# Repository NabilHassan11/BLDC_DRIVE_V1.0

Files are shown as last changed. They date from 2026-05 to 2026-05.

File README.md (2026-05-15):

# BLDC Drive

A 3-phase Brushless DC (BLDC) motor driver PCB designed in KiCad, capable of handling **12V** supply voltage at **10–25A** continuous phase current.

---

## 📸 Board Preview

<!-- Replace the placeholder below with your actual board image -->
<!-- > 📷 **[Insert top-view board photo or 3D render here]** -->

BLDC Drive Top View

---

## ✨ Features

- **Input Voltage:** 12V
- **Output Current:** 10–25A (per phase, depending on thermal management)
- **Gate Driver:** IR2110 half-bridge drivers (×3 — one per phase)
- **Power MOSFETs:** IRFZ44VZPBF N-channel MOSFETs in a 3-phase full-bridge configuration (6× total)
- **Current Sensing:** INA180A3 rail-to-rail current sense amplifiers
- **Bulk Decoupling:** 470µF electrolytic capacitors for supply filtering
- **EMI Filtering:** WE-CBF 0805 ferrite beads and 100nF bypass capacitors
- **Board Size:** 80mm × 80mm, 2-layer PCB
- **Connectors:** JST XH series
- **Designed with:** KiCad 8.0

---

## 🖼 Schematic

<!-- Add schematic image or PDF link below -->
> 📐 **[Insert schematic screenshot or link here]**

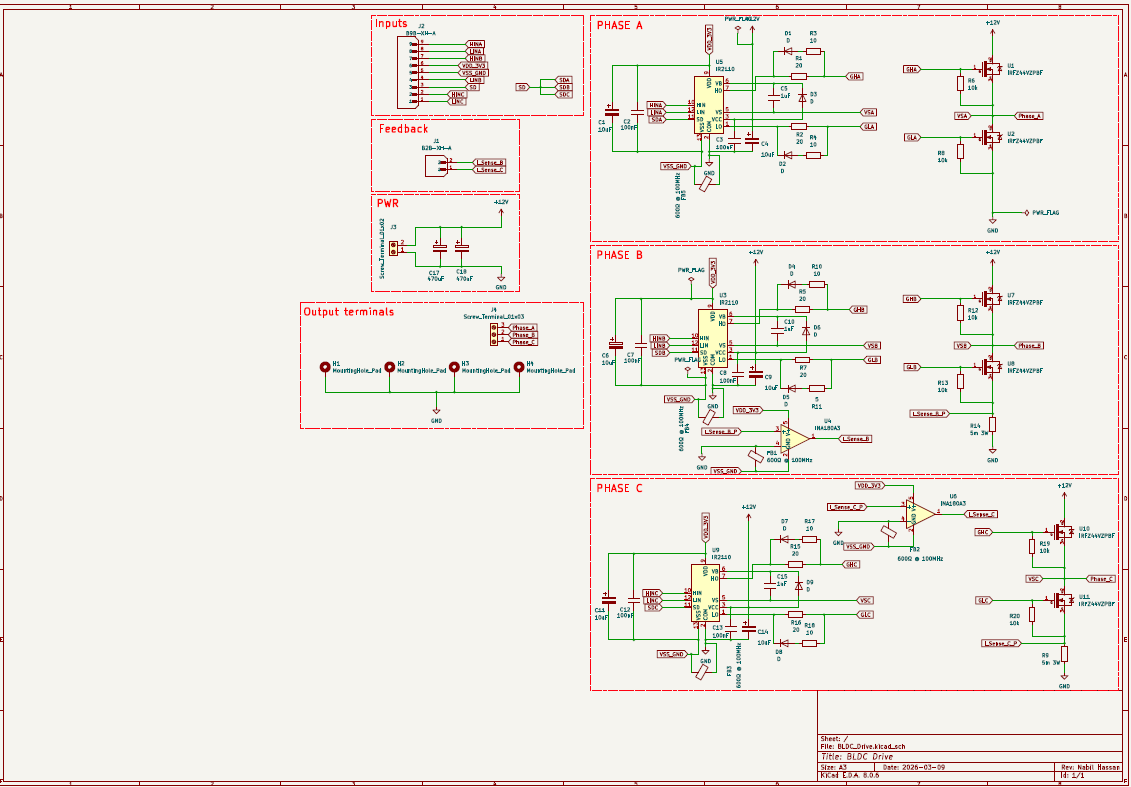
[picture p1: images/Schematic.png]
Schematic

<!-- Or link to the PDF: -->
<!-- [View Full Schematic (PDF)](BLDC_Drive/plots/BLDC_Drive__Assembly.pdf) -->
-->

---

## 🔩 Bill of Materials (BOM)

| Designator | Component | Value / Part Number | Description |
|---|---|---|---|
| Q1–Q6 | N-Channel MOSFET | IRFZ44VZPBF | Power switch, TO-220 |
| U1–U3 | Gate Driver | IR2110 | Half-bridge gate driver |
| U4–U6 | Current Sense Amp | INA180A3 | Rail-to-rail, 100V/V gain, SOT-23-5 |
| C_bulk | Electrolytic Cap | 470µF | Bulk supply decoupling |
| C_bypass | Ceramic Cap | 100nF | High-freq bypass |
| C_gate | Ceramic Cap | 1µF / 10µF | Gate drive bootstrap / filtering |
| R_sense | Shunt Resistor | 5mΩ 3W | Phase current sensing |
| R_gate | Resistor | 5Ω / 10Ω / 20Ω | Gate resistance |
| FB1–FBx | Ferrite Bead | WE-CBF 0805, 600Ω@100MHz | EMI filtering |
| J_motor | JST B9B-XH-A | 9-pin | Motor phase + hall sensor connector |
| J_signal | JST B2B-XH-A | 2-pin | Signal/control connector |
| — | Screw Terminals | 2-pin, 3-pin | Power input/output terminals |

> 📋 **Full interactive BOM:** [`BLDC_Drive/bom/ibom.html`](BLDC_Drive/bom/ibom.html)

---

## 📁 Repository Structure

```
BLDC_Drive/
├── BLDC_Drive/
│   ├── BLDC_Drive.kicad_sch         # Schematic
│   ├── BLDC_Drive.kicad_pcb         # PCB layout
│   ├── BLDC_Drive.kicad_pro         # KiCad project file
│   ├── bom/
│   │   └── ibom.html                # Interactive BOM
│   ├── Drill Files/                 # PTH and NPTH drill files
│   ├── gerber_to_order/             # Ready-to-order Gerbers
│   │   ├── BLDC_Drive_80.0x80.0mm_for_JLCPCB/
│   │   ├── BLDC_Drive_80.0x80.0mm_for_Elecrow/
│   │   ├── BLDC_Drive_80.0x80.0mm_for_PCBWay/
│   │   └── BLDC_Drive_80.0x80.0mm_for_FusionPCB/
│   └── plots/
│       └── BLDC_Drive__Assembly.pdf # Assembly drawing
├── AOD4184A/                        # KiCad library: AOD4184A MOSFET
├── IRFZ44VZPBF/                     # KiCad library: IRFZ44VZPBF MOSFET
├── LIB_DRV8353SRTAR/                # KiCad library: DRV8353 gate driver
├── B2B-XH-A/ & B9B-XH-A/           # KiCad library: JST connectors
├── LM358P/                          # KiCad library: LM358 op-amp
├── WE-CBF_0805/                     # KiCad library: ferrite bead
└── cap_calculator.jsx               # Bootstrap capacitor calculator tool
```

---

## 🖼 PCB Layout

<!-- Add PCB layout images below -->

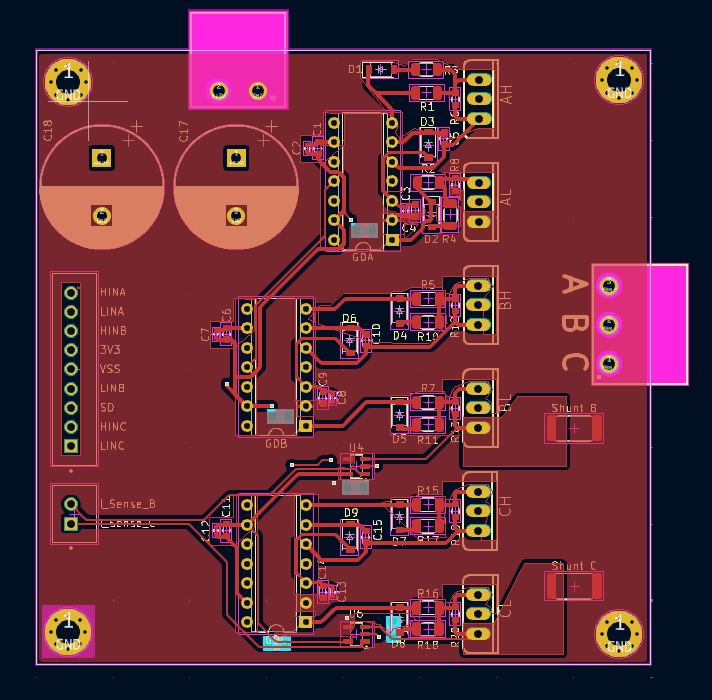
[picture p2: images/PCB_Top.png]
PCB Top Layer

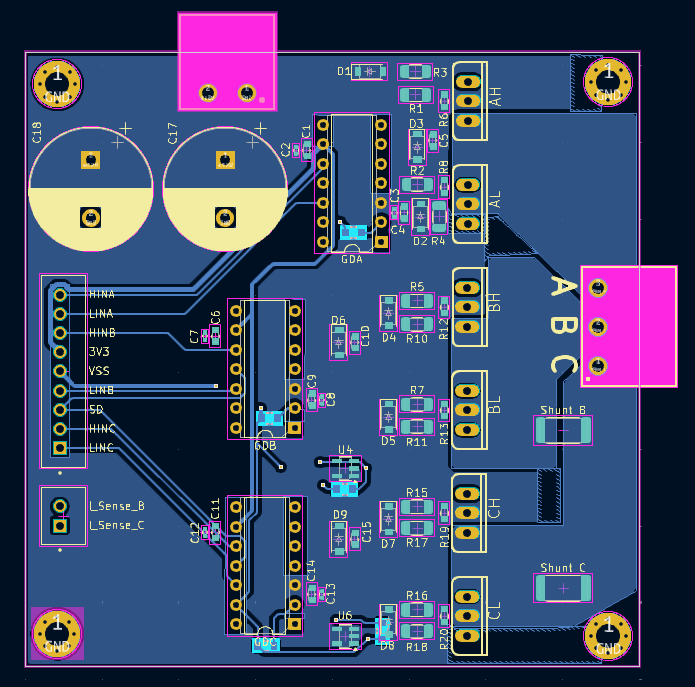
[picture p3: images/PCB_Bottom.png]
PCB Bottom Layer


---

## 🚀 Getting Started

### Requirements

- [KiCad 8.0](https://www.kicad.org/) or later
- A 12V DC power supply rated for at least 25A
- PWM control signals (typically from a microcontroller or dedicated BLDC controller)

### Opening the Project

1. Clone or download this repository.
2. Open KiCad and select **File → Open Project**.
3. Navigate to `BLDC_Drive/BLDC_Drive.kicad_pro`.
4. Import the custom component libraries from the component folders (see `how-to-import.htm` inside each folder).

### Ordering PCBs

Pre-generated Gerber files are available for major manufacturers inside `BLDC_Drive/gerber_to_order/`. Simply upload the appropriate `.zip` file to your fab of choice:

| Manufacturer | Gerber Package |
|---|---|
| JLCPCB | `BLDC_Drive_80.0x80.0mm_for_JLCPCB.zip` |
| PCBWay | `BLDC_Drive_80.0x80.0mm_for_PCBWay.zip` |
| Elecrow | `BLDC_Drive_80.0x80.0mm_for_Elecrow.zip` |
| FusionPCB | `BLDC_Drive_80.0x80.0mm_for_FusionPCB.zip` |

Recommended PCB specs: **2 layers, 2oz copper, HASL or ENIG finish.**

---

## ⚡ Electrical Specifications

| Parameter | Value |
|---|---|
| Supply Voltage (V_bus) | 12V |
| Continuous Phase Current | 10–25A |
| MOSFET V_DS rating | 60V (IRFZ44VZPBF) |
| MOSFET I_D rating | 55A (IRFZ44VZPBF) |
| Gate Driver Bootstrap voltage | 12V |
| Current sense gain | 100 V/V (INA180A3) |
| Shunt resistance | 5mΩ |

---

## ⚠️ Warnings & Safety Notes

- Always ensure proper heat sinking on the power MOSFETs (Q1–Q6) when operating above 10A.
- Do not exceed **12V** on the V_bus input without verifying all component voltage ratings.
- Verify gate drive bootstrap capacitor values using the included `cap_calculator.jsx` tool before assembling.
- The board does not include overcurrent protection hardware — implement this in firmware or add an external fuse rated for your load.
- This board is designed for **DC brushless motors only**. Do not connect it to AC loads.

---

## 🔧 Assembly Notes

> 🔩 **[Insert assembled board photo here]**

<!-- Example:
![Assembled Board](images/assembled.jpg)
-->

- Begin soldering with the smallest SMD components first (ferrite beads, bypass caps, SOT-23 ICs).
- Solder power MOSFETs and screw terminals last.
- Refer to the interactive BOM (`bom/ibom.html`) for component placement guidance.
- The assembly drawing PDF (`plots/BLDC_Drive__Assembly.pdf`) can be printed as a reference during assembly.

---

## 👤 Author

**Nabil Hassan**
Revision date: 2026-03-09

---

## 🤝 Contributing

Pull requests and issue reports are welcome. If you find a bug in the schematic or layout, please open an issue with a description and reference designators.

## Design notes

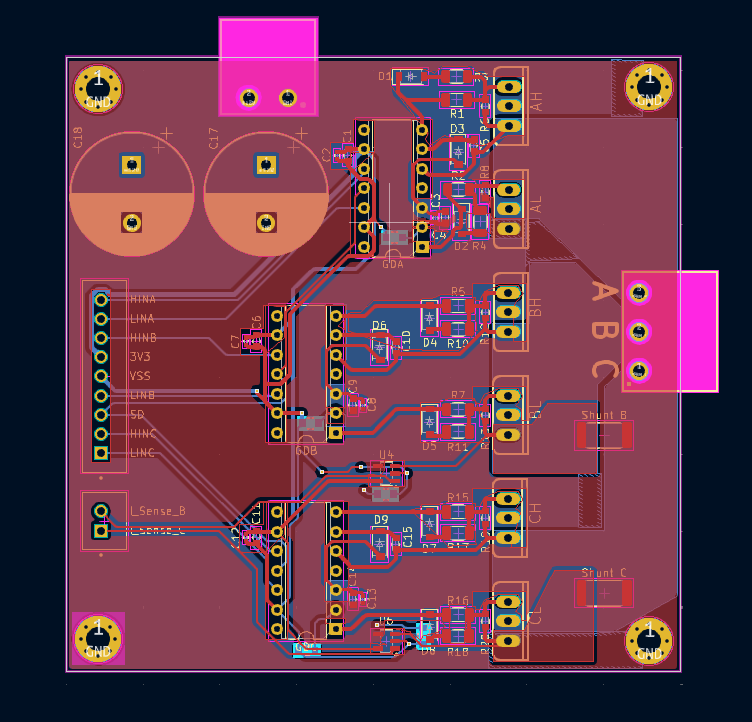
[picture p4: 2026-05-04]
images/PCB.png

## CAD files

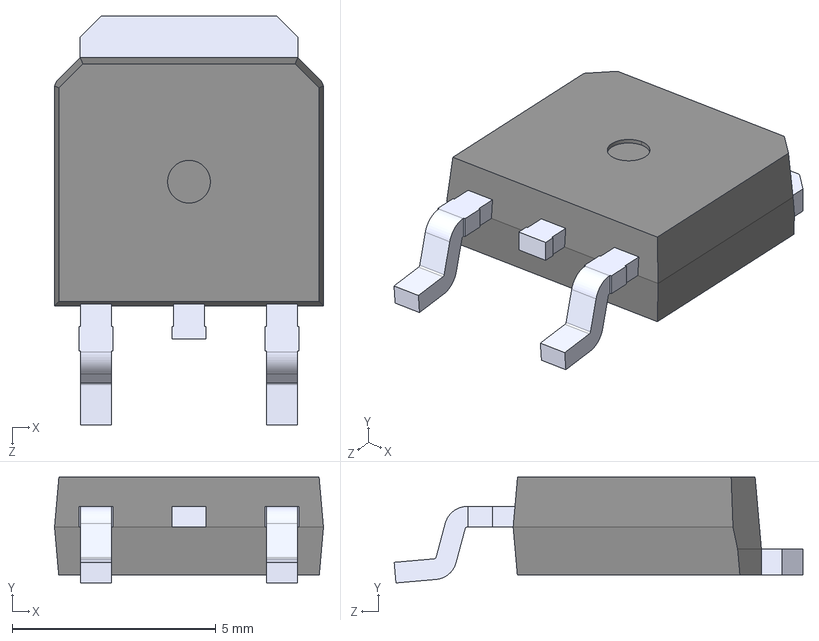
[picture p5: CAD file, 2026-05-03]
AOD4184A/AOD4184A.step
6.60 x 2.60 x 10.0 mm

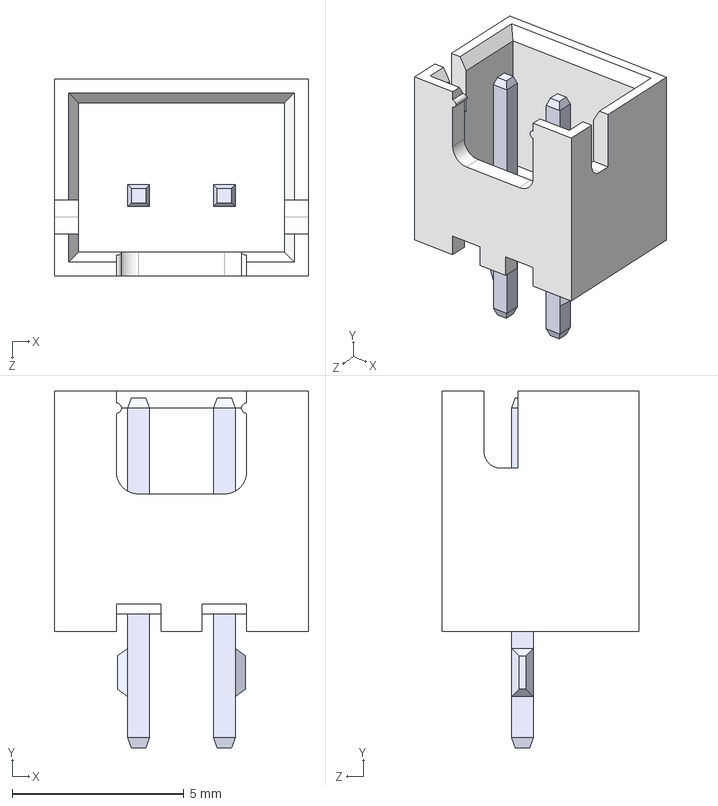
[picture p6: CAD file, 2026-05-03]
B2B-XH-A/B2B-XH-A.step
7.40 x 10.4 x 5.75 mm

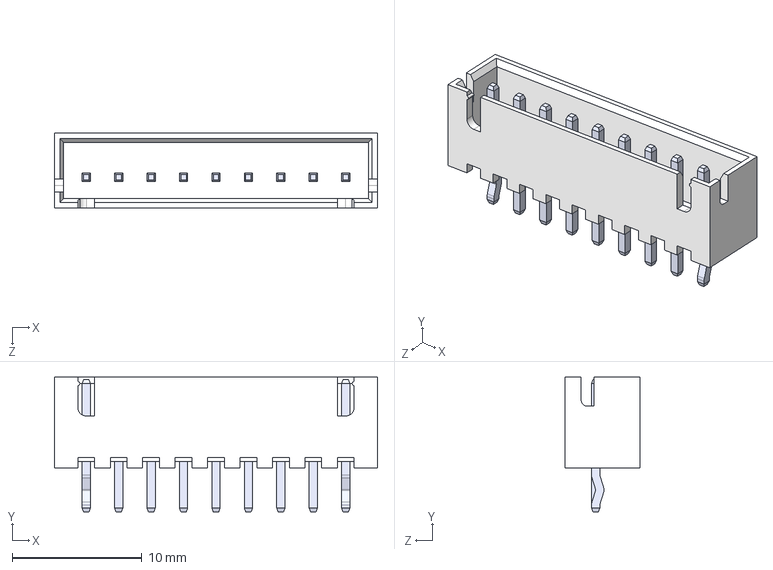
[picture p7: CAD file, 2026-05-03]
B9B-XH-A/B9B-XH-A.step
24.9 x 10.4 x 5.75 mm

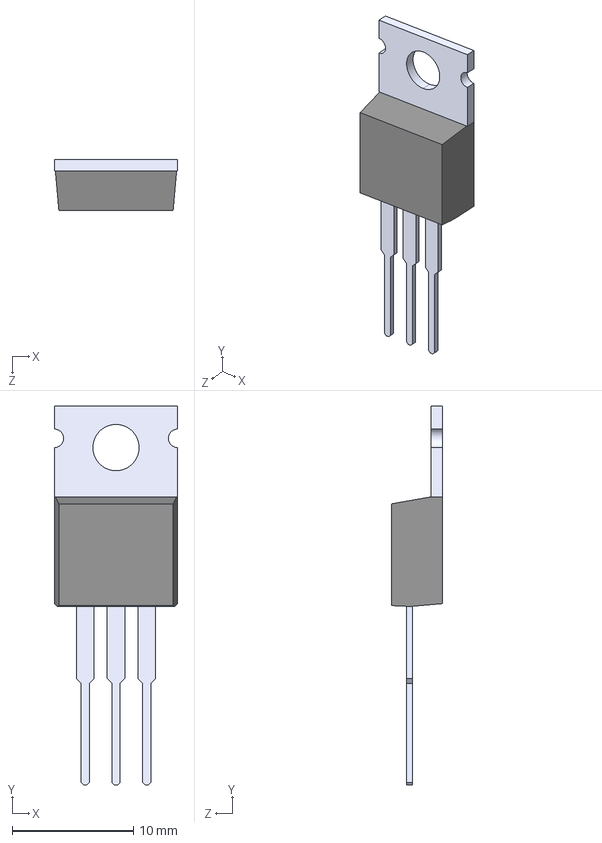
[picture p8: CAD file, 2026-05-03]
IRFZ44VZPBF/IRFZ44VZPBF.step
10.2 x 31.2 x 4.19 mm

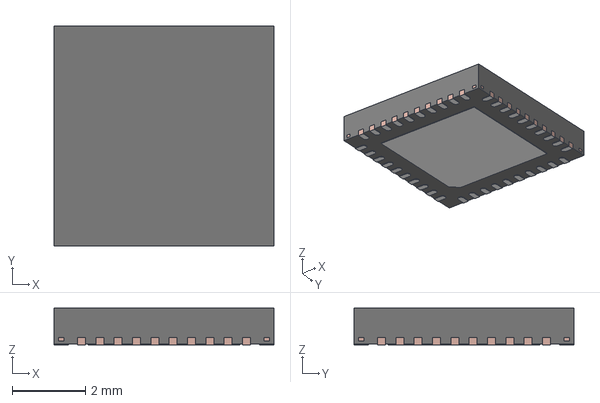
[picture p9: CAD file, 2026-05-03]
LIB_DRV8353SRTAR/DRV8353SRTAR/3D/DRV8353SRTAR.stp
6.00 x 6.00 x 1.00 mm
FRAME

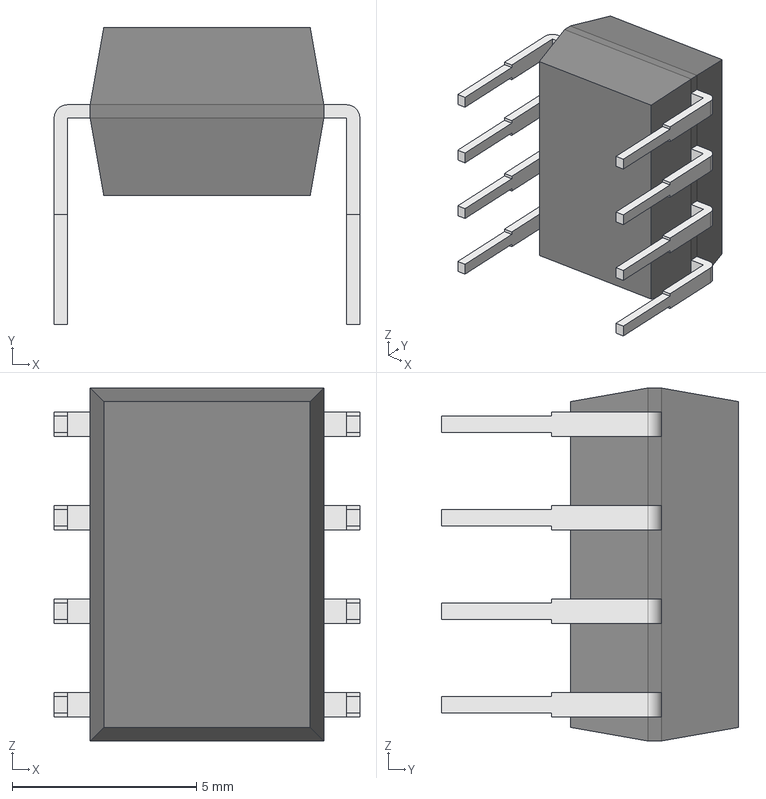
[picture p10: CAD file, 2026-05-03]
LM358P/LM358P.step
8.31 x 8.08 x 9.59 mm
Body001 (Mirror #1) x 5

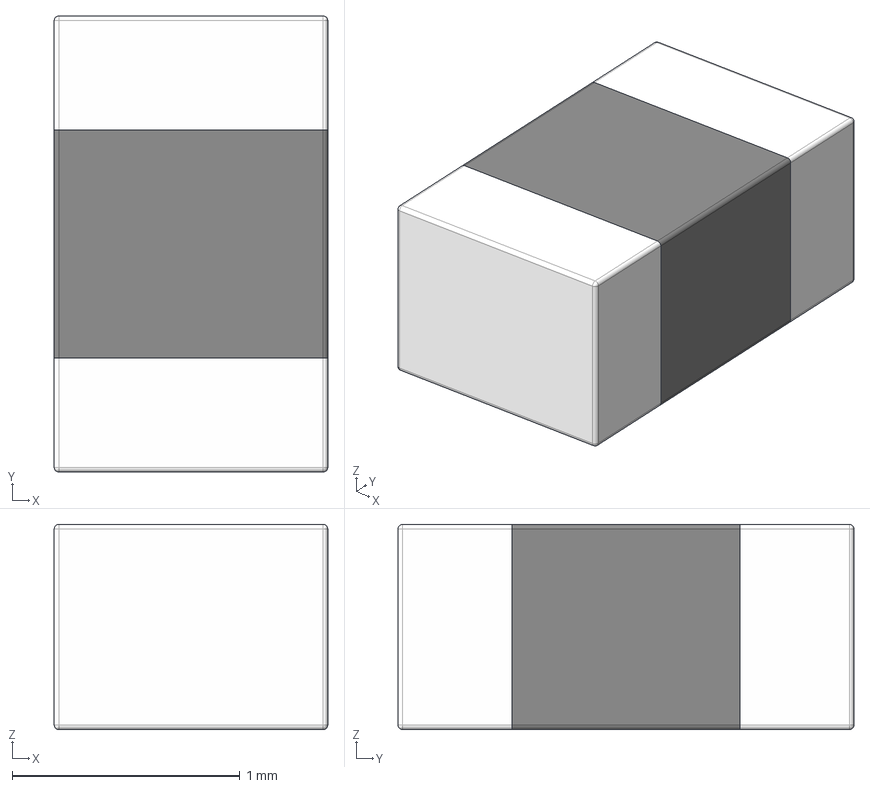
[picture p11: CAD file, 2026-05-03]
WE-CBF_0805/WE-CBF_0805.step
1.20 x 2.00 x 0.9 mm
Lötende x 2

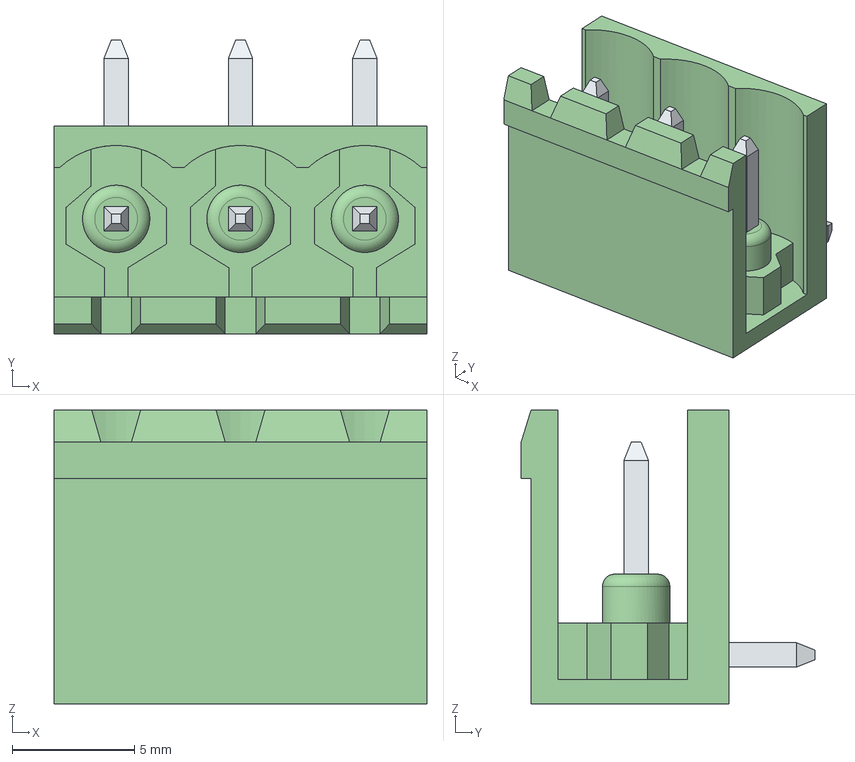
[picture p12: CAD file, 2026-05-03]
691312510003/691312510003.step
15.2 x 12.0 x 12.0 mm
6913125100xx_PIN x 3

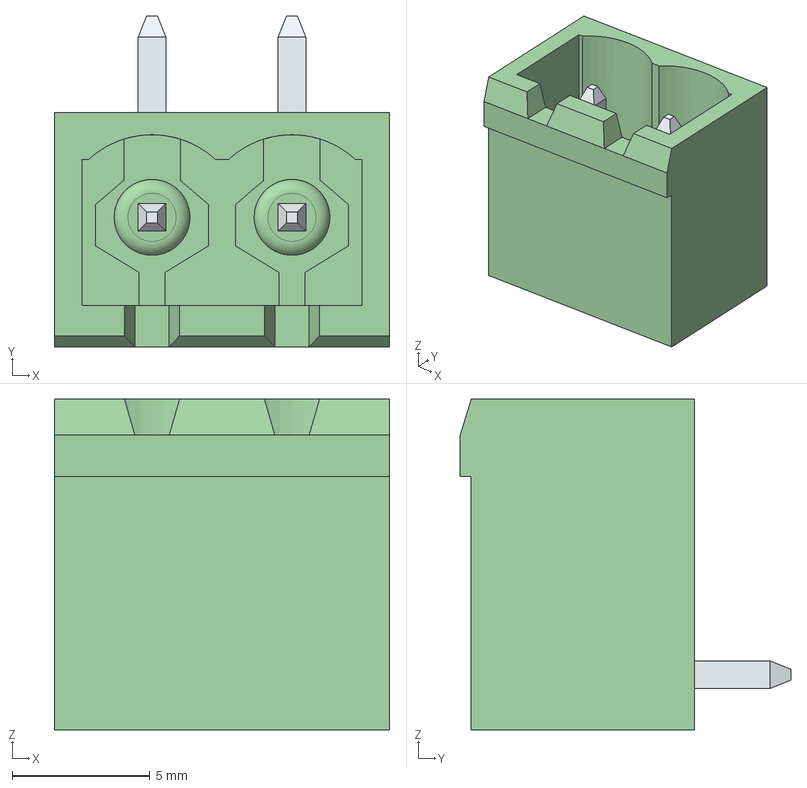
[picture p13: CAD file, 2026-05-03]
691313510002/691313510002.step
12.2 x 12.0 x 12.0 mm
6913135100xx_PIN x 2

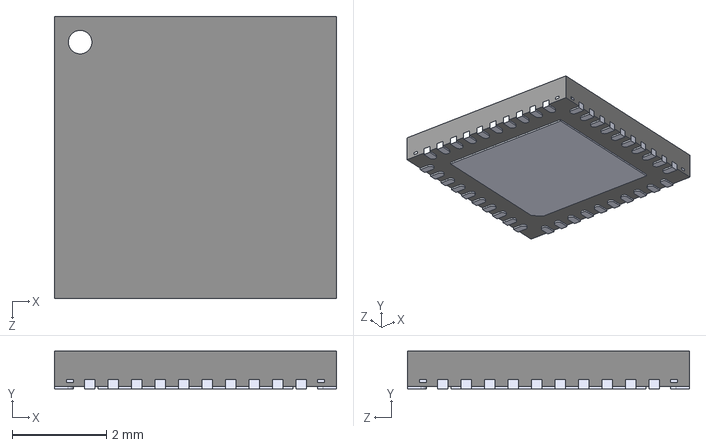
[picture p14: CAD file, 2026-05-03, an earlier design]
LIB_DRV8353SRTAR (1)/DRV8353SRTAR/KiCad/QFN50P600X600X80-41N/QFN50P600X600X80-41N.step
6.00 x 0.8 x 6.00 mm

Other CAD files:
LIB_DRV8353SRTAR (1)/DRV8353SRTAR/Allegro/qfn50p600x600x80-41n-d.psm
LIB_DRV8353SRTAR (1)/DRV8353SRTAR/DEHDL/drv8353srtar/chips/chips.prt
LIB_DRV8353SRTAR/DRV8353SRTAR/Allegro/qfn50p600x600x80-41n-d.psm
LIB_DRV8353SRTAR/DRV8353SRTAR/DEHDL/drv8353srtar/chips/chips.prt

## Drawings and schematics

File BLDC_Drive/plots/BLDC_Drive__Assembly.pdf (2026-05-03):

# GDC BL CH AH

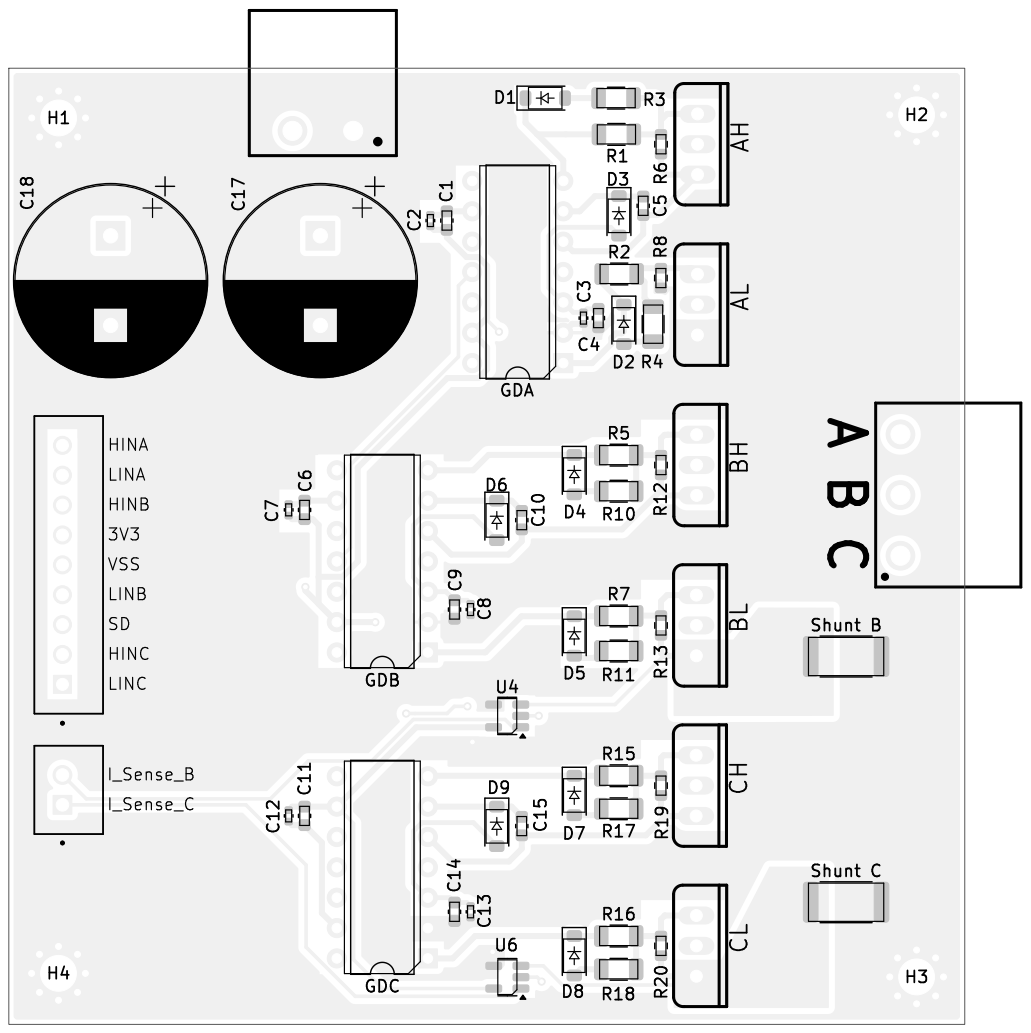
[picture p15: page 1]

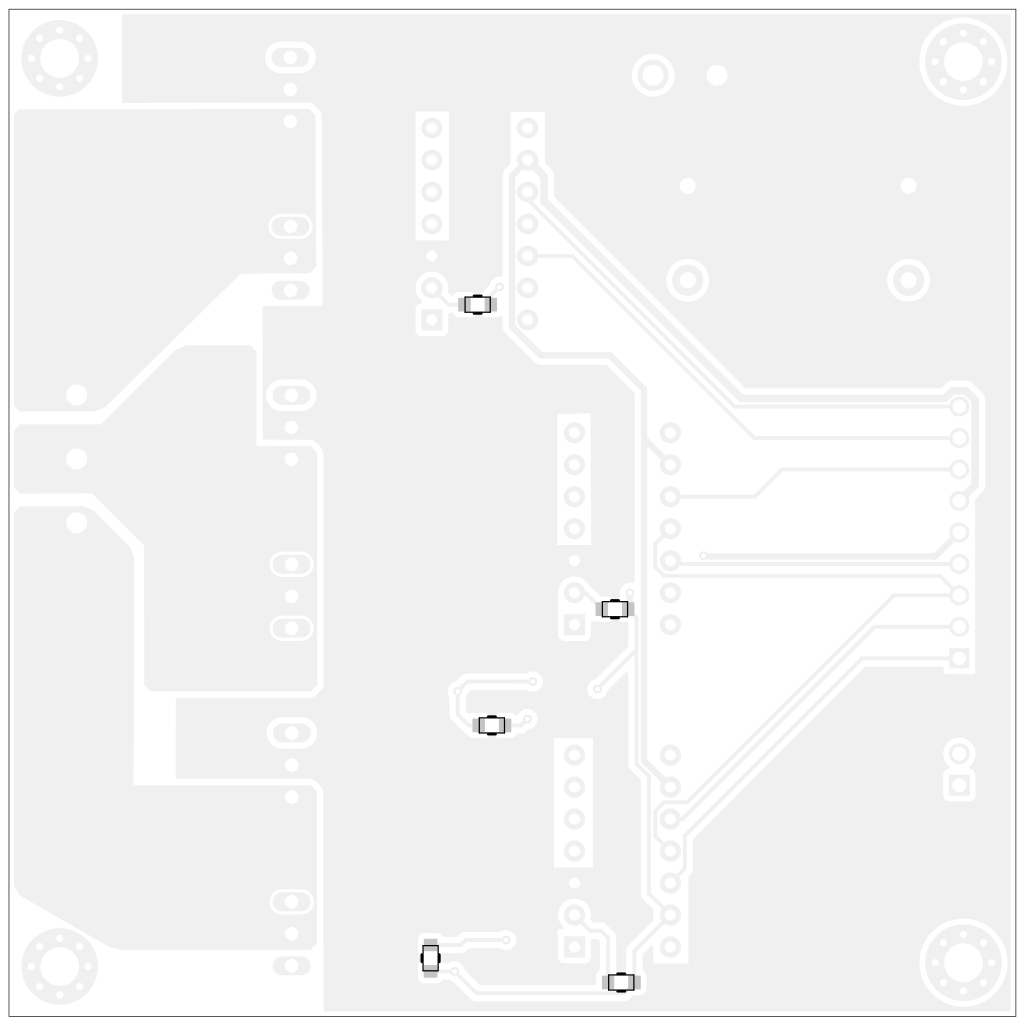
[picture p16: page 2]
D Date: KiCad; E.D.A. 8.0.6 Size: A4; Rev:; Id: 1/1 Title: File: BLDC_Drive.kicad_pcb Sheet: Black; And; White; BOT Board2Pdf:; Black; BOT -; Page 2/8

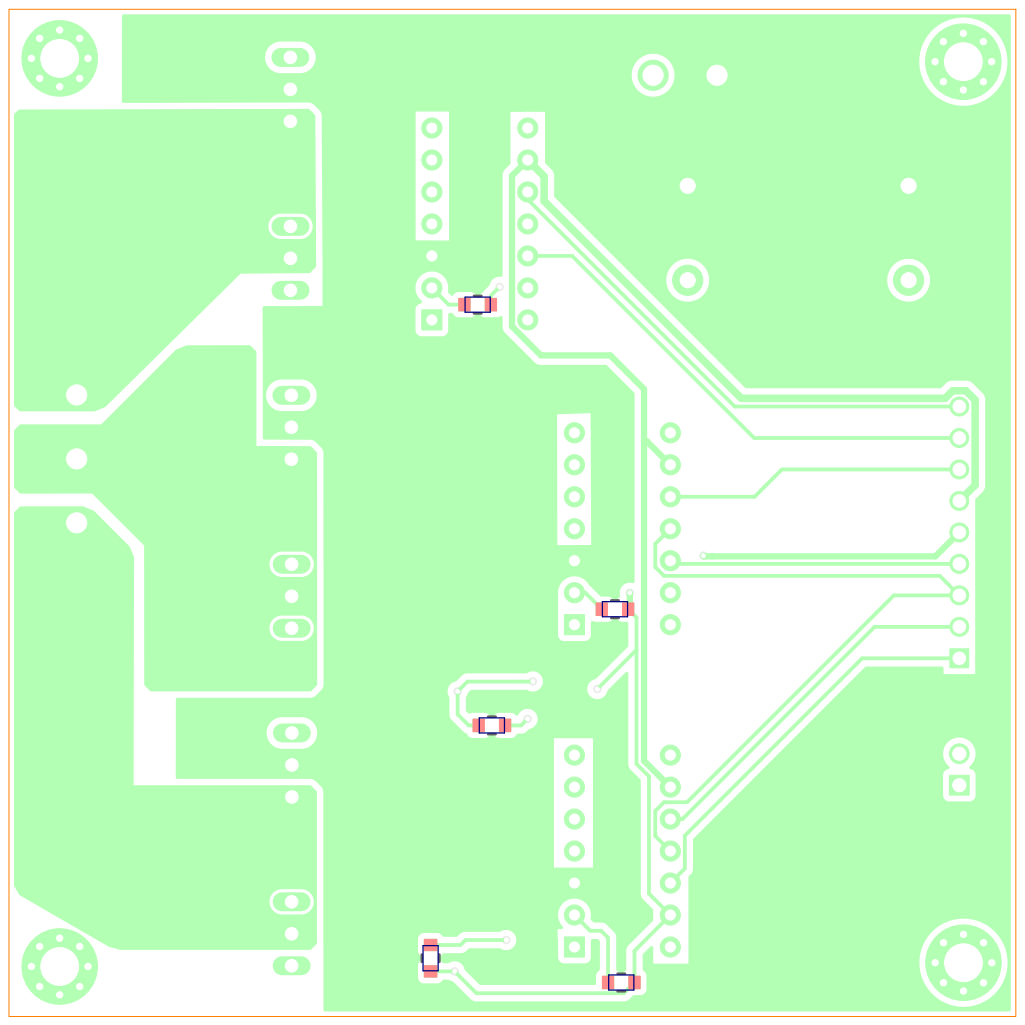
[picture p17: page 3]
D Date: KiCad; E.D.A. 8.0.6 Size: A4; Rev:; Id: 1/1 Title: File: BLDC_Drive.kicad_pcb Sheet: Colored; BOT Board2Pdf:; Colored; BOT -; Page 3/8

# GDC BL CH AH

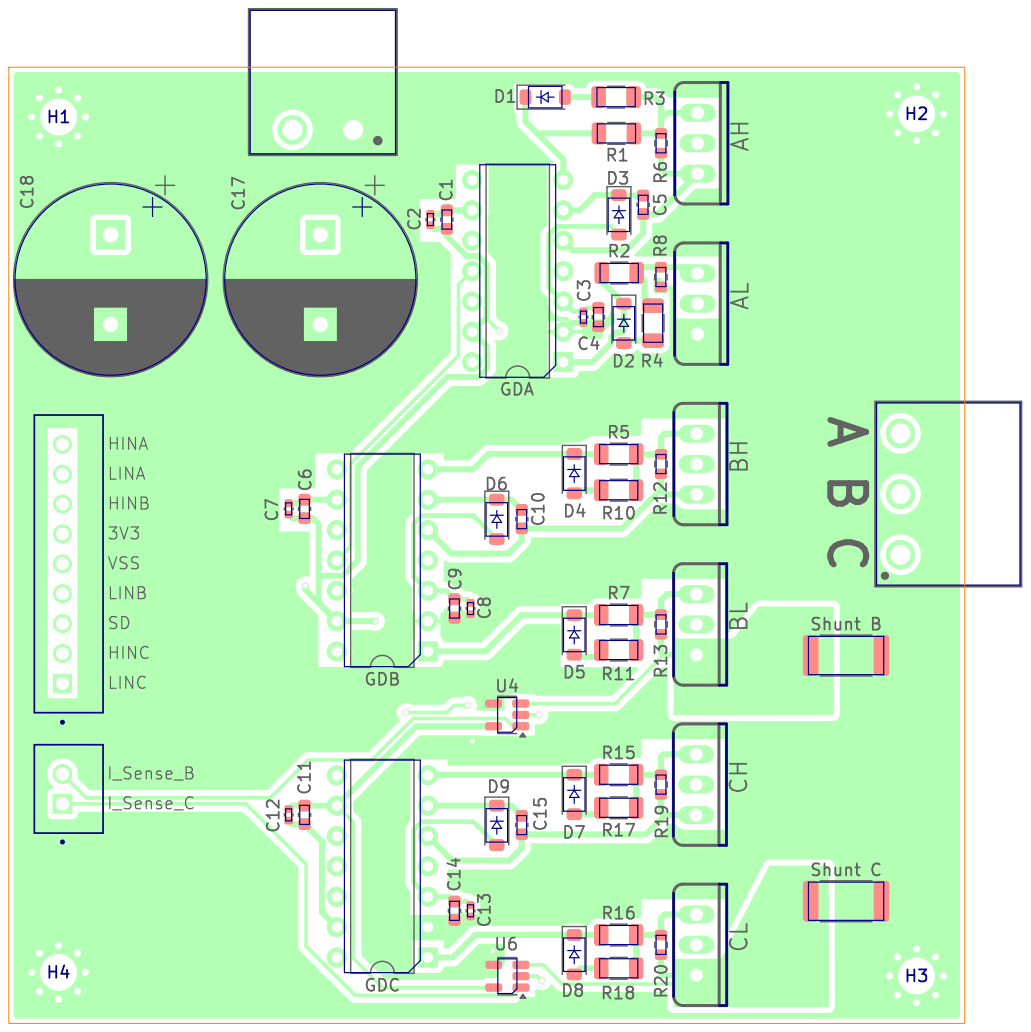
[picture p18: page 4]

# GDC BL CH AH

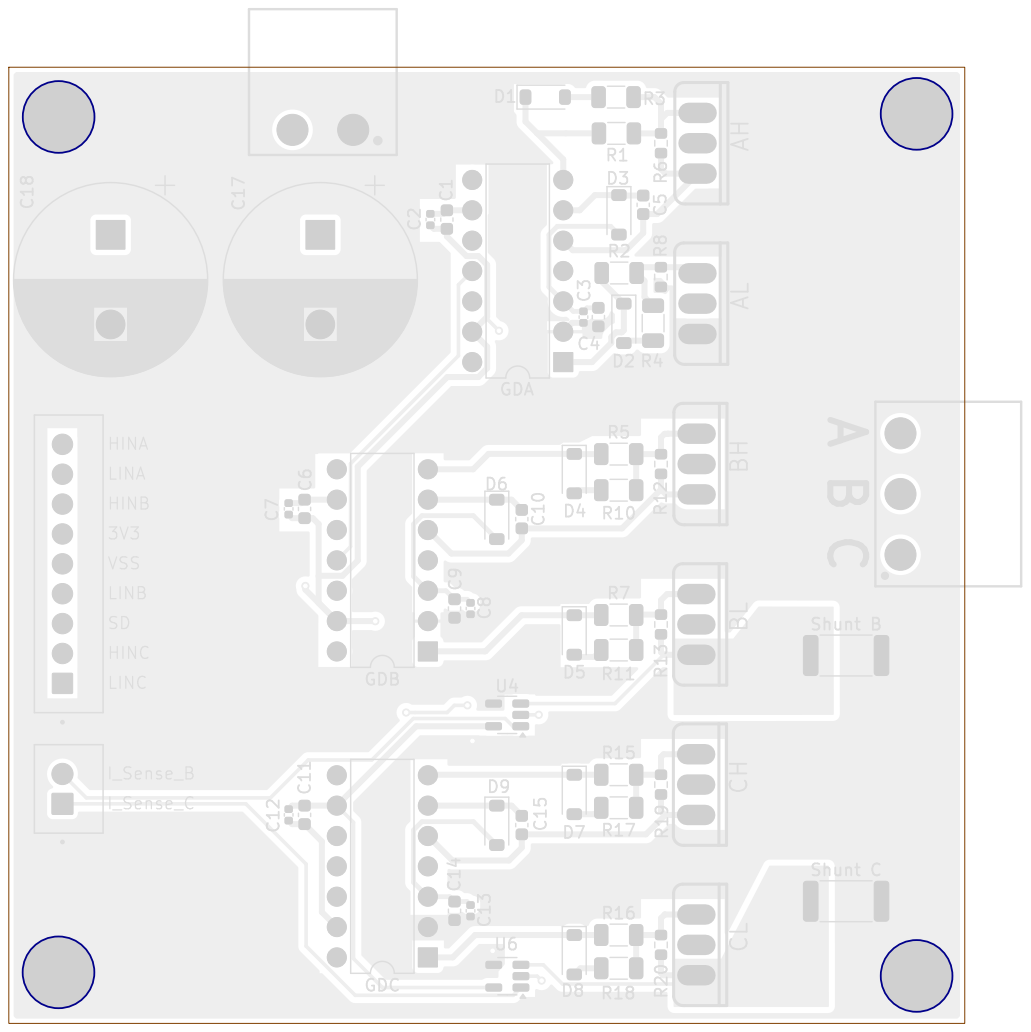
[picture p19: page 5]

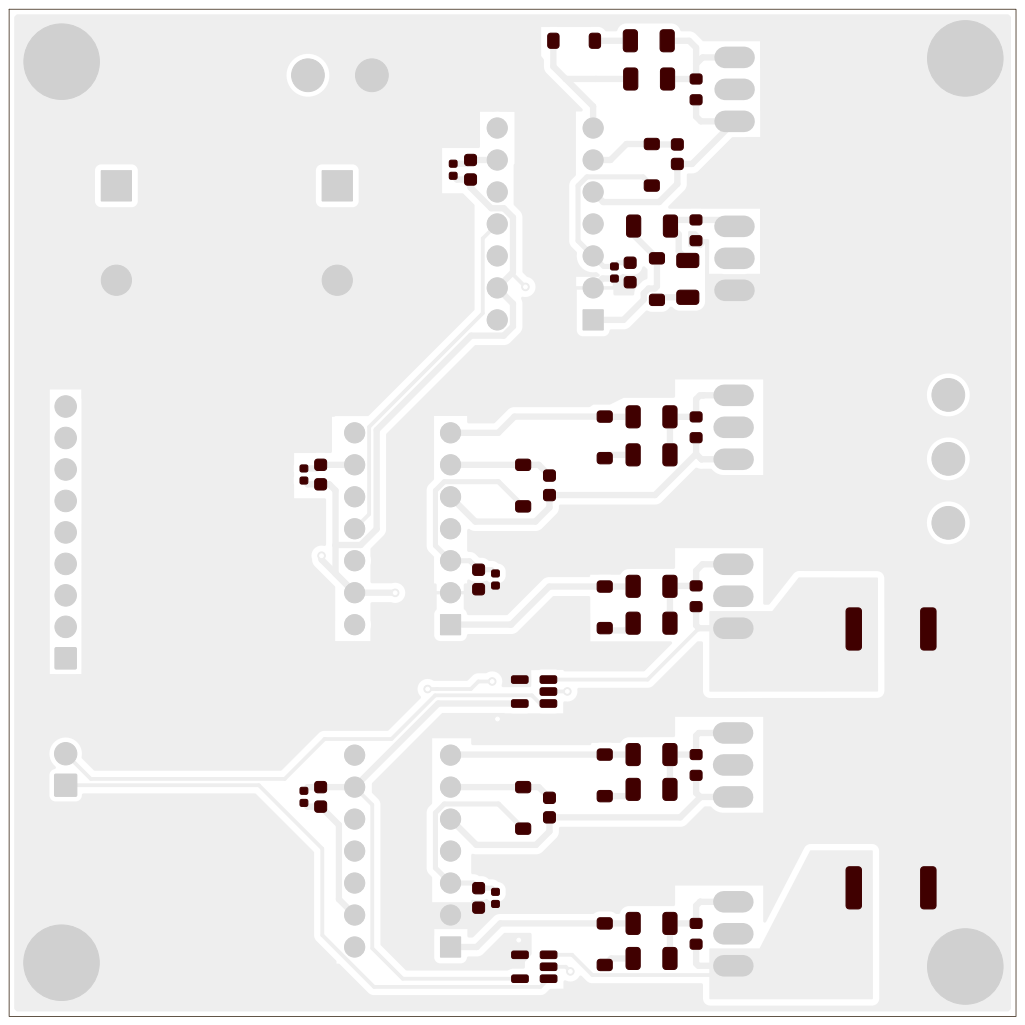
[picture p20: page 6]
D Date: KiCad; E.D.A. 8.0.6 Size: A4; Rev:; Id: 1/1 Title: File: BLDC_Drive.kicad_pcb Sheet: Light Colors; PCB; Paste; TOP; Board2Pdf:; Light Colors; TOP -; Page 6/8

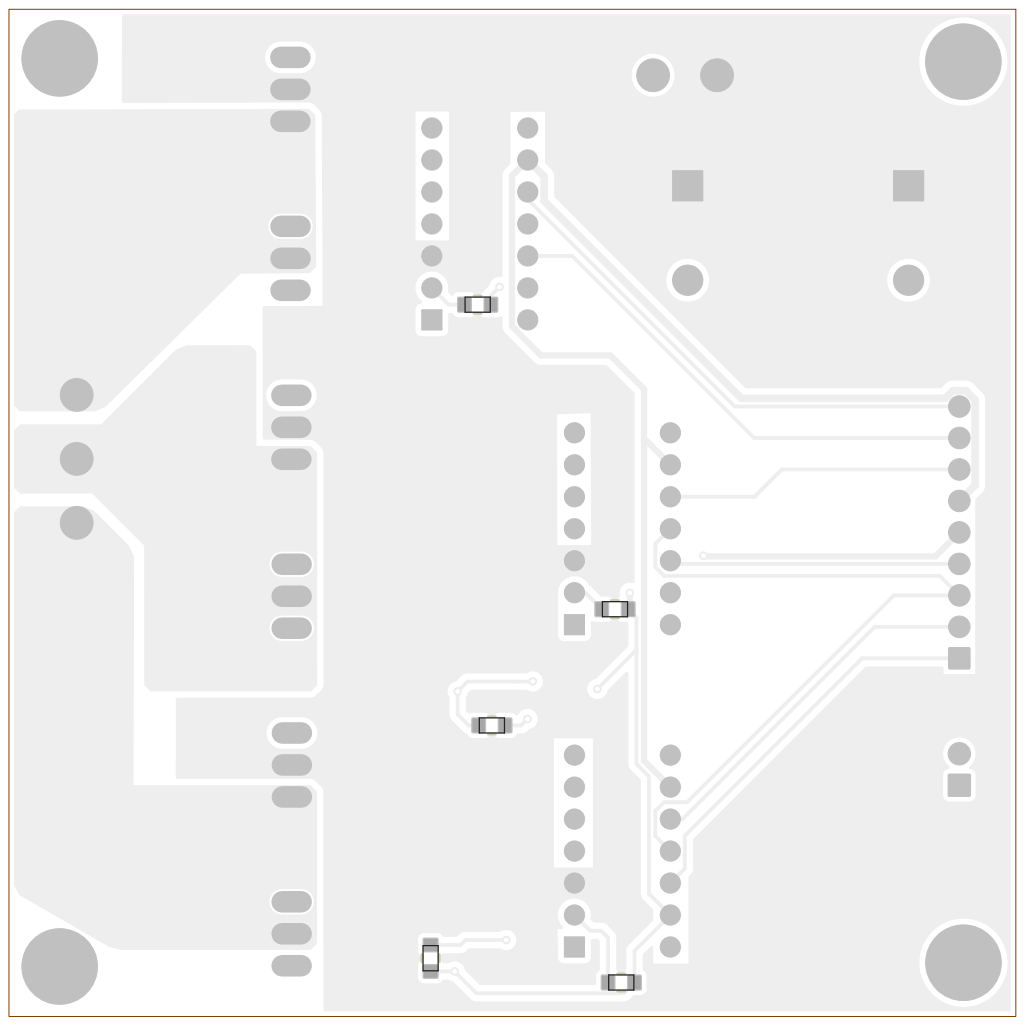
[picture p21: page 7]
D Date: KiCad; E.D.A. 8.0.6 Size: A4; Rev:; Id: 1/1 Title: File: BLDC_Drive.kicad_pcb Sheet: Light Colors; Placement; BOT Board2Pdf:; Light Colors; BOT -; Page 7/8

# GDC BL CH AH

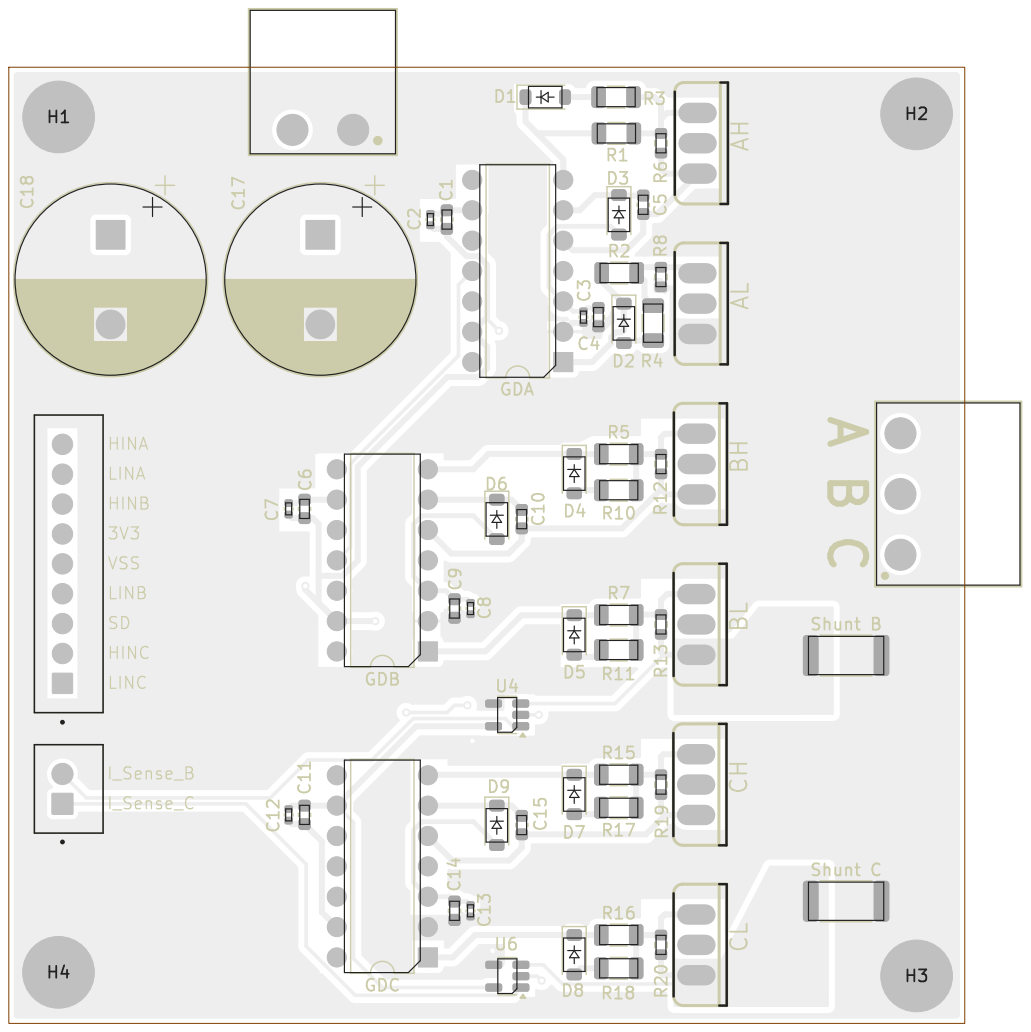
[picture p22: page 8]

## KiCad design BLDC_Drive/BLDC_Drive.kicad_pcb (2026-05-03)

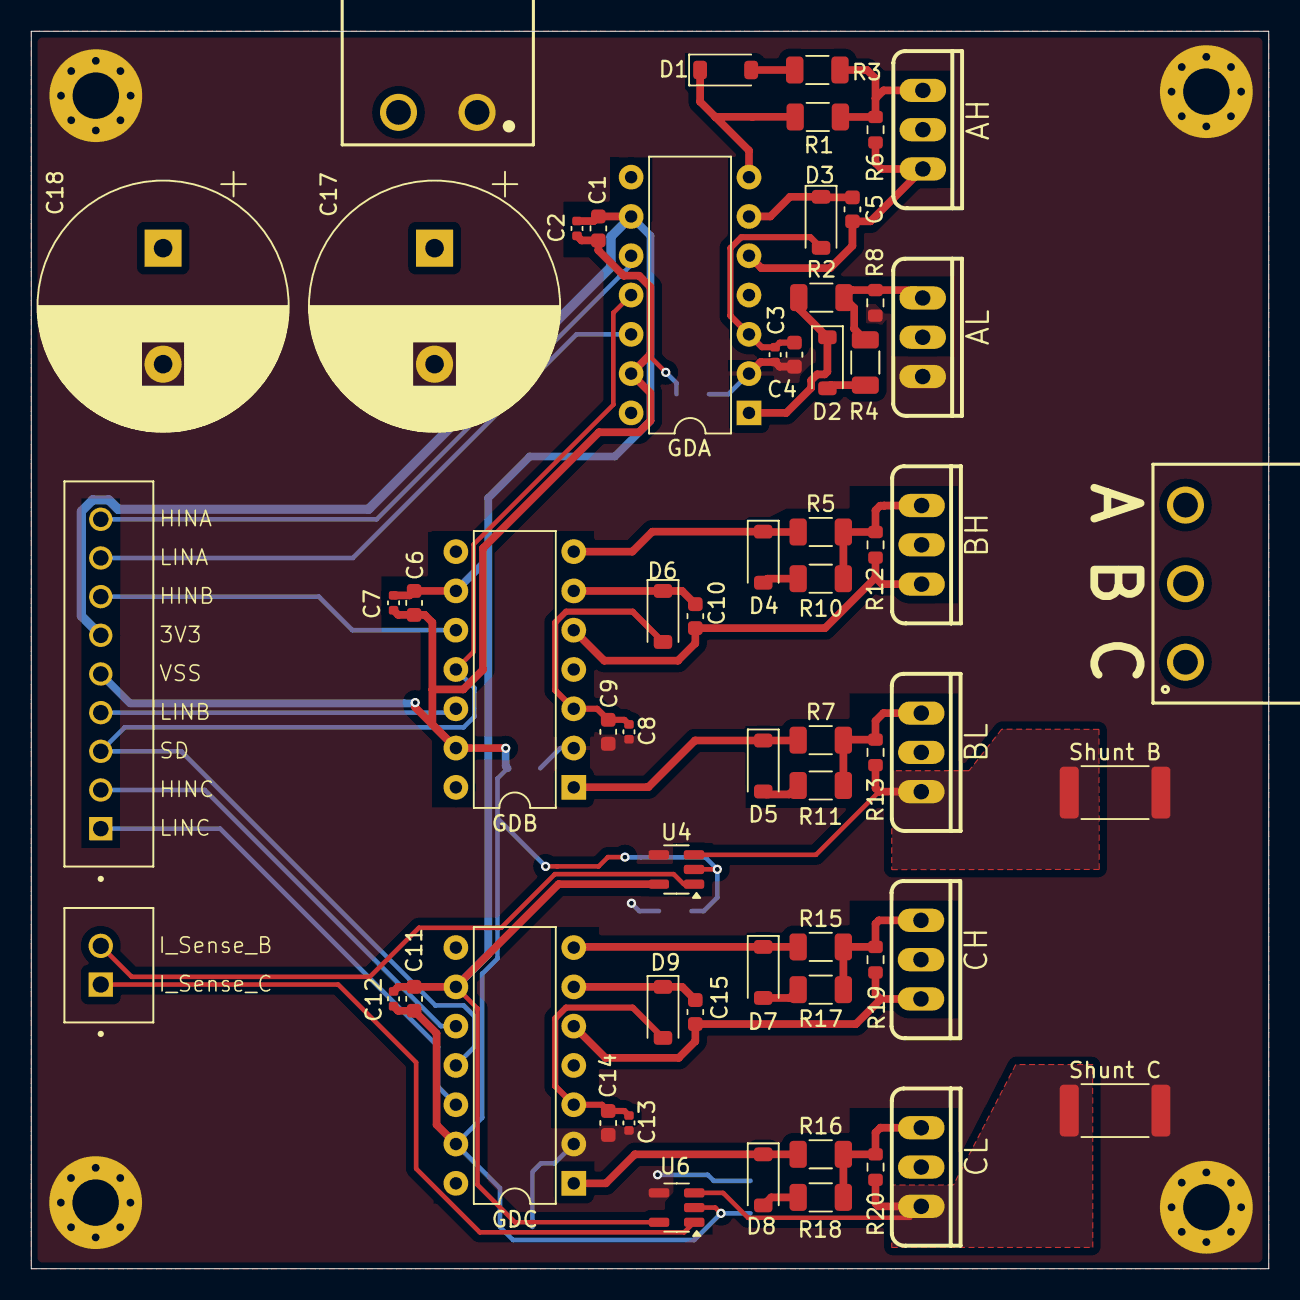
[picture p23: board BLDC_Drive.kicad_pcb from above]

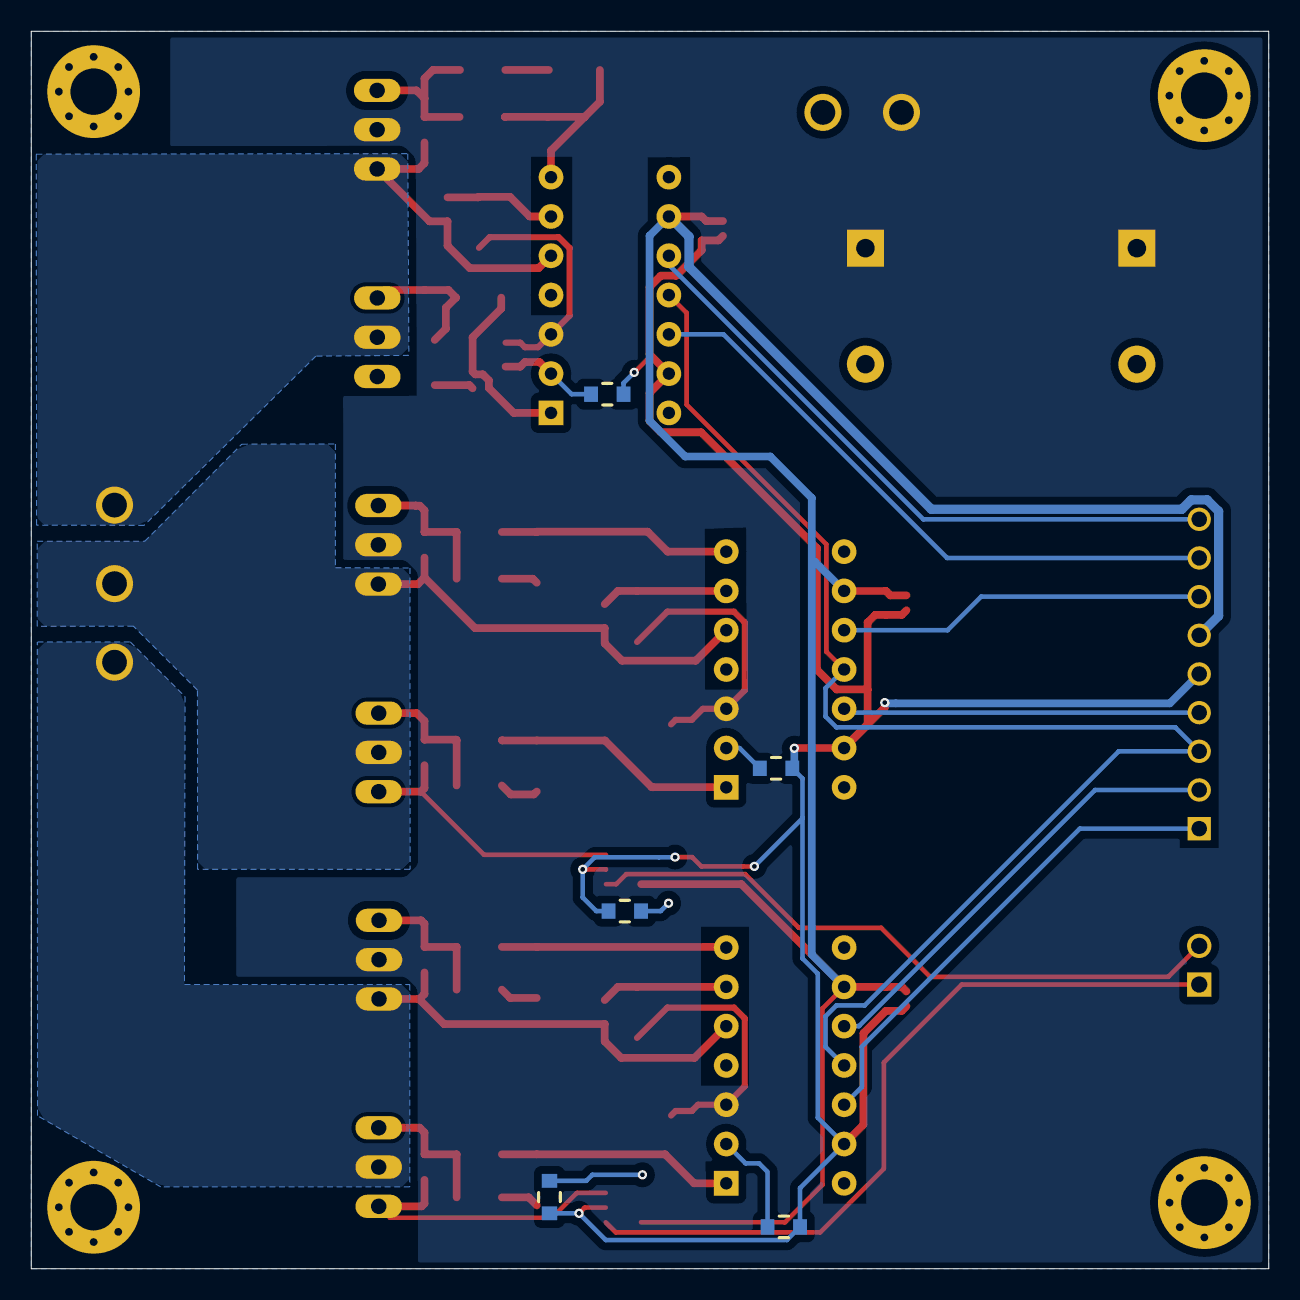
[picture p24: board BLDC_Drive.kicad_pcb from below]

Board: 2 copper layers, 80.0 x 80.0 mm, 70 parts (5 on the bottom side), 39 nets.

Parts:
AH: IRFZ44VZPBF; TO-220
AL: IRFZ44VZPBF; TO-220
BH: IRFZ44VZPBF; TO-220
BL: IRFZ44VZPBF; TO-220
C1, C4, C6, C9, C11, C14: 10uF; C_0603_1608Metric
C2, C3, C7, C8, C12, C13: 100nF; C_0402_1005Metric
C5, C10, C15: 1uF; C_0603_1608Metric
C17, C18: 470uF; CP_Radial_D16.0mm_P7.50mm
CH: IRFZ44VZPBF; TO-220
CL: IRFZ44VZPBF; TO-220
D1, D2, D3, D4, D5, D6, D7, D8, D9: D; D_SOD-123
FB1, FB2, FB3, FB4, FB5: 600Ω @ 100MHz; WE-CBF_0805_W3.0
GDA: IR2110; DIP-14_W7.62mm
GDB: IR2110; DIP-14_W7.62mm
GDC: IR2110; DIP-14_W7.62mm
H1, H2, H3, H4: MountingHole_Pad; MountingHole_3mm_Pad_Via
J1: B2B-XH-A; JST_B2B-XH-A
J2: B9B-XH-A; JST_B9B-XH-A
J3: Screw_Terminal_01x02; 691313510002
J4: Screw_Terminal_01x03; 691312510003
R1, R2, R5, R7, R15, R16: 20; R_1206_3216Metric
R3, R4, R10, R17, R18: 10; R_1206_3216Metric
R6, R8, R12, R13, R19, R20: 10k; R_0603_1608Metric
R11: 5; R_1206_3216Metric
Shunt B: 5m 3W; R_2512_6332Metric
Shunt C: 5m 3W; R_2512_6332Metric
U4, U6: INA180A3; SOT-23-5

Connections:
+12V: AH.2, BH.2, C3.1, C4.1, C8.1, C9.1, C13.1, C14.1, C17.1, C18.1, CH.2, D3.2 (A), D6.2 (A), D9.2 (A), GDA.3 (VCC), GDB.3 (VCC), GDC.3 (VCC), J3.2
GHA: AH.1, R1.2, R3.2, R6.1
GHB: BH.1, R5.2, R10.2, R12.1
GHC: CH.1, R15.2, R17.2, R19.1
GLA: AL.1, R2.2, R4.1, R8.1
GLB: BL.1, R7.2, R11.1, R13.1
GLC: CL.1, R16.2, R18.1, R20.1
GND: AL.3, C3.2, C4.2, C8.2, C9.2, C13.2, C14.2, C17.2, C18.2, FB1.1, FB2.1, FB3.2, FB4.2, FB5.2, GDA.2 (COM), GDB.2 (COM), GDC.2 (COM), H1.1, H2.1, H3.1, H4.1, J3.1, R8.2, Shunt B.2, Shunt C.2, U4.4 (-), U6.4 (-)
HINA: GDA.10 (HIN), J2.9
HINB: GDB.10 (HIN), J2.7
HINC: GDC.10 (HIN), J2.2
I_Sense_B: J1.2, U4.1
I_Sense_B_P: BL.3, R13.2, Shunt B.1, U4.3 (+)
I_Sense_C: J1.1, U6.1
I_Sense_C_P: CL.3, R20.2, Shunt C.1, U6.3 (+)
LINA: GDA.12 (LIN), J2.8
LINB: GDB.12 (LIN), J2.4
LINC: GDC.12 (LIN), J2.1
unnamed: D1.2 (A), R3.1
unnamed: D1.1 (K), GDA.7 (HO), R1.1
unnamed: D2.2 (A), R4.2
unnamed: D2.1 (K), GDA.1 (LO), R2.1
unnamed: C5.1, D3.1 (K), GDA.6 (VB)
unnamed: D4.2 (A), R10.1
unnamed: D4.1 (K), GDB.7 (HO), R5.1
unnamed: D5.2 (A), R11.2
unnamed: D5.1 (K), GDB.1 (LO), R7.1
unnamed: C10.1, D6.1 (K), GDB.6 (VB)
unnamed: D7.2 (A), R17.1
unnamed: D7.1 (K), GDC.7 (HO), R15.1
unnamed: D8.2 (A), R18.2
unnamed: D8.1 (K), GDC.1 (LO), R16.1
unnamed: C15.1, D9.1 (K), GDC.6 (VB)
Phase_A: AH.3, AL.2, C5.2, GDA.5 (VS), J4.3, R6.2
Phase_B: BH.3, BL.2, C10.2, GDB.5 (VS), J4.2, R12.2
Phase_C: C15.2, CH.3, CL.2, GDC.5 (VS), J4.1, R19.2
SD: GDA.11 (SD), GDB.11 (SD), GDC.11 (SD), J2.3
VDD_3V3: C1.1, C2.1, C6.1, C7.1, C11.1, C12.1, GDA.9 (VDD), GDB.9 (VDD), GDC.9 (VDD), J2.6, U4.5 (V+), U6.5 (V+)
VSS_GND: C1.2, C2.2, C6.2, C7.2, C11.2, C12.2, FB1.2, FB2.2, FB3.1, FB4.1, FB5.1, GDA.13 (VSS), GDB.13 (VSS), GDC.13 (VSS), J2.5, U4.2 (GND), U6.2 (GND)

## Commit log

2026-05-03 Added PCB files
    [691312510003.step, 691313510002.step, AOD4184A.step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]
2026-05-03 Add link to BLDC Drive top view image in README
    Updated README to include a link to the BLDC Drive top view image.
2026-05-04 Update bldc_drive_top images
2026-05-04 Added BLDC DRIVE Image
2026-05-04 Revise connector details and power terminal description
    Updated connector information and clarified power terminal description.
2026-05-15 Update README to remove PCB image placeholder
    Removed placeholder for PCB top copper layer image.
